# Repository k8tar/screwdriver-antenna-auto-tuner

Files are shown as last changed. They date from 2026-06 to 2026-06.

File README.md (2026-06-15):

# Screwdriver Antenna Auto Tuner

An ESP32-based automatic controller for motorized HF screwdriver antennas.

This repository contains the firmware, generated KiCad design files, enclosure
model, sourcing notes, build documentation, renders, and fabrication outputs for
an in-vehicle automatic antenna tuner with:

- ESP32 control logic
- OLED status display
- motor drive with current-based stall detection
- SWR measurement using an onboard directional coupler
- detachable radio and antenna harnesses
- Tarheel-style sensor support via the 4-wire antenna connector

## Current revision highlights

- single-mode auto-tuner firmware with TUNE, PARK, and jog controls
- power-stage revision to the Murata OKI-78SR fixed 3.3 V regulator
- external SWR jack removed from the PCB revision
- updated enclosure previews and board renders
- regenerated Gerber package in `fab/tuner_gerbers.zip`
- printable enclosure assets can be exported directly from OpenSCAD, with 3MF
	files generated for the current base and lid geometry

## Screenshots

Board render:

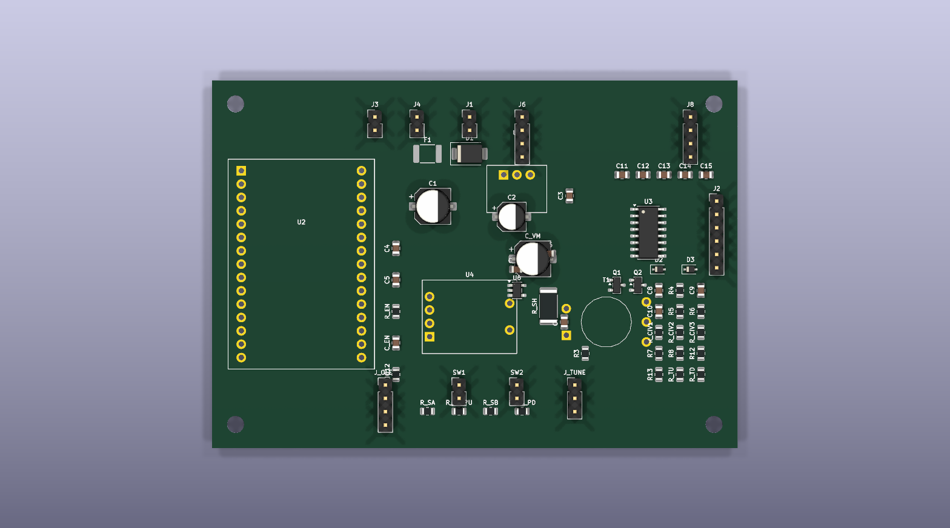
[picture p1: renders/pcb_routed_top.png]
Routed PCB top


Assembled enclosure preview:

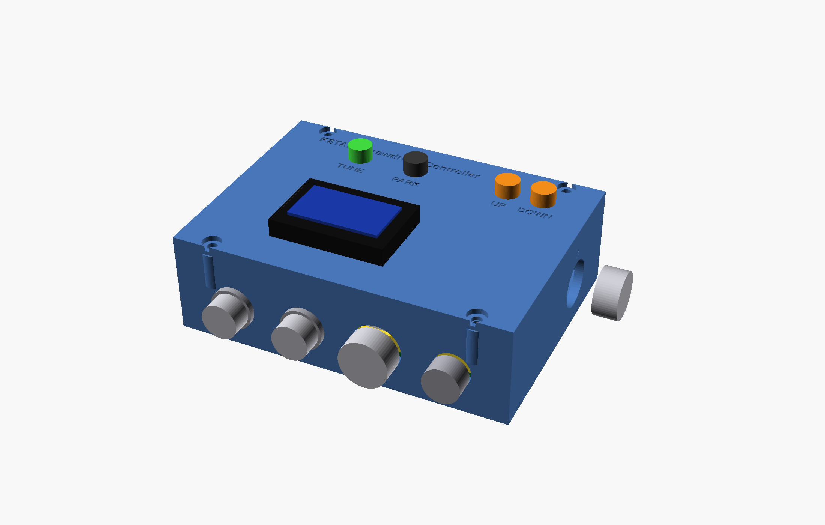
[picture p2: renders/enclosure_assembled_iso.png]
Enclosure assembled isometric


Service-open enclosure preview:

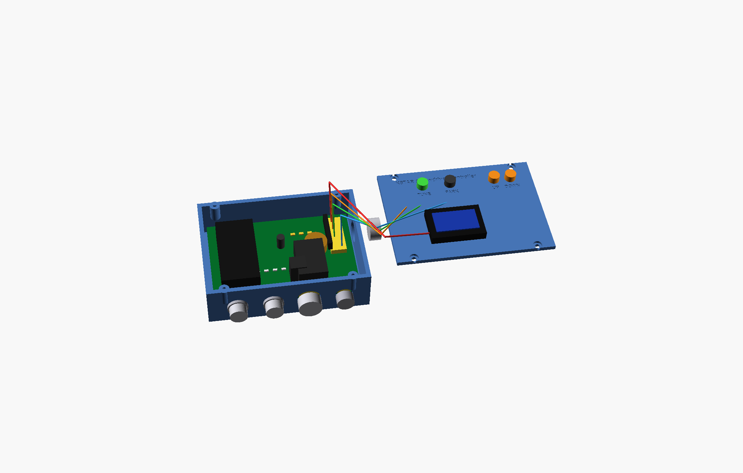
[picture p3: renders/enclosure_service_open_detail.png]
Enclosure service-open detail


## Repository layout

- `firmware/` — PlatformIO firmware, simulation wiring, and firmware spec
- `hardware/` — assembly guide, BOM, sourcing, routing notes, enclosure model
- `hardware/kicad/` — generated KiCad schematic, PCB, netlist, DSN, footprints
- `renders/` — board and enclosure images plus schematic and PCB PDFs
- `fab/` — generated Gerbers and fabrication ZIP package
- `scripts/` — source-of-truth generators for schematic, PCB, BOM, and fab outputs

## Quick start

1. Read the hardware requirements and build notes in `hardware/ASSEMBLY.md`.
2. Review the firmware contract in `firmware/FIRMWARE_SPEC.md`.
3. Build firmware from `firmware/` with PlatformIO.
4. If you are fabricating the PCB, use `fab/tuner_gerbers.zip`.
5. If you are printing the enclosure, use the generated 3MF files in
	`hardware/enclosure/` or export fresh parts from `hardware/enclosure/enclosure.scad`.

## First-time builder checklist

1. Read `hardware/ASSEMBLY.md` start to finish before soldering anything.
2. Confirm you are building the **Murata OKI-78SR** power-stage revision, not the older adjustable U1 variant.
3. Order parts from `hardware/BOM.csv` and review substitutions in `hardware/SOURCING.md`.
4. Verify your enclosure connector choices against `hardware/RADIO_CONNECTOR.md` and `hardware/enclosure/README.md`.
5. Print or export the enclosure parts you want before final panel-harness lengths are cut.
6. Build and test the firmware in `firmware/` before final in-vehicle installation.
7. Power the assembled board from a current-limited bench supply first.
8. Program the ESP32 DevKit over USB and verify the OLED, buttons, PARK, and jog behavior before connecting the antenna.
9. Run `PARK` once after wiring a Tarheel-style sensor harness so the controller establishes home.

## Prerequisites

- Python 3 for the generator scripts
- PlatformIO for firmware builds
- KiCad CLI available through the configured Flatpak commands for schematic/PCB regeneration
- OpenSCAD for enclosure previews and print-file export

## Build and generation

Firmware build:

```bash
cd firmware
pio run
```

Firmware upload:

```bash
cd firmware
pio run -t upload
pio device monitor
```

Hardware regeneration from the repo root:

```bash
python3 scripts/gen_footprints.py
python3 scripts/gen_schematic.py
flatpak run --command=kicad-cli org.kicad.KiCad sch export netlist -o hardware/kicad/tuner.net hardware/kicad/tuner.kicad_sch
flatpak run --command=python3 org.kicad.KiCad scripts/gen_pcb.py
flatpak run --command=python3 org.kicad.KiCad scripts/export_dsn.py
python3 scripts/gen_bom.py
python3 scripts/gen_gerbers.py
```

Enclosure print export:

```bash
cd hardware/enclosure
openscad -D 'part="base"' -o base.stl enclosure.scad
openscad -D 'part="lid"' -o lid.stl enclosure.scad
openscad -D 'part="both"' -o enclosure_full.stl enclosure.scad
openscad -D 'part="base"' -o base.3mf enclosure.scad
openscad -D 'part="lid"' -o lid.3mf enclosure.scad
openscad -D 'part="both"' -o enclosure_full.3mf enclosure.scad
```

## Primary documentation

- `firmware/FIRMWARE_SPEC.md`
- `firmware/src/README.md`
- `hardware/ASSEMBLY.md`
- `hardware/SOURCING.md`
- `hardware/RADIO_CONNECTOR.md`
- `hardware/enclosure/README.md`

## Fabrication outputs

- PCB fabrication ZIP: `fab/tuner_gerbers.zip`
- Individual Gerbers/drill files: `fab/gerbers/`
- Enclosure print files: `hardware/enclosure/base.stl`, `hardware/enclosure/lid.stl`, `hardware/enclosure/enclosure_full.stl`, `hardware/enclosure/base.3mf`, `hardware/enclosure/lid.3mf`, `hardware/enclosure/enclosure_full.3mf`
- Board and enclosure previews: `renders/`

## Programming the ESP32

This design uses an ESP32 DevKit module as `U2`, so the easiest programming path
is through the DevKit's normal USB port.

Typical workflow:

1. Assemble the board and fit the ESP32 DevKit at `U2`.
2. Power the board from a current-limited 12 V bench supply for first bring-up.
3. Connect the ESP32 DevKit USB port to your computer.
4. From the `firmware/` directory, run:

```bash
pio run -t upload
pio device monitor
```

If you ever need direct serial flashing instead of the DevKit USB connector, use
the debug UART header `J8` with a 3.3 V USB-to-UART adapter.

Recommended `J8` signals:

- pin 1 = GND
- pin 2 = 3V3
- pin 3 = TX from ESP32
- pin 4 = RX to ESP32

For most builds, you do **not** need to power the ESP32 through `J8`; just share
ground and use the DevKit USB interface unless you have a special recovery case.

## Notes

- The generated KiCad files in `hardware/kicad/` are derived artifacts; the
	Python scripts in `scripts/` are the source of truth.
- For vehicle use, internal board wiring should be direct-soldered and strain
	relieved rather than using loose jumper leads.
- The pre-generated STL and 3MF files are convenience outputs for the current
	enclosure geometry; regenerate them from `hardware/enclosure/enclosure.scad` if
	you change any enclosure parameters. `enclosure_full.3mf` and
	`enclosure_full.stl` contain the base and lid together as one combined export.

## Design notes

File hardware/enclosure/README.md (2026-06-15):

# Enclosure — 3D-printed, two-part

Parametric OpenSCAD box for the tuner PCB. **`enclosure.scad`** builds two parts:
a **base** tray (holds the PCB, carries the rear panel-mount connectors) and a
**lid** (the control panel — OLED, TUNE/PARK, jog).

## Dimensions
- Outer **110 × 80 × 34 mm** (fits the 100 × 70 board with 2 mm clearance).
- All driven by parameters at the top of the `.scad`; change `board_l/w`,
  `comp_clear` (headroom), `gap`, `wall`, `standoff_h` and everything re-derives.

## Rendering / exporting
```
openscad -D 'part="base"' -o base.stl  enclosure.scad
openscad -D 'part="lid"'  -o lid.stl   enclosure.scad
openscad -D 'part="both"' -o enclosure_full.stl enclosure.scad
openscad -D 'part="base"' -o base.3mf enclosure.scad
openscad -D 'part="lid"'  -o lid.3mf  enclosure.scad
openscad -D 'part="both"' -o enclosure_full.3mf enclosure.scad
# preview both side-by-side in the GUI: set part="both"
```

Pre-generated print files for the current repo revision:

- `base.stl`
- `lid.stl`
- `enclosure_full.stl` (base and lid exported together in one STL)
- `base.3mf`
- `lid.3mf`
- `enclosure_full.3mf` (base and lid exported together in one 3MF)

Additional preview modes in `enclosure.scad`:

- `part="assembled"` closed enclosure with installed board/components
- `part="lid_off"` lifted lid with wiring still connected
- `part="service_open"` lid fully moved to the side with long service loops

RF connector cutout in `enclosure.scad` is fixed for compact Mini-UHF bulkheads:

- `rf_bulkhead_d = 10.0` (Mini-UHF panel hole)
- Selected connector model: **Amphenol RF 172147** (Mouser)

Optional RF mounting screw-hole pattern:

- `rf_mount_holes = true` enables two M3 clearance holes per RF connector.
- `rf_mount_hole_d` sets the screw hole diameter.
- `rf_mount_hole_pitch` sets screw center-to-center spacing.

Set `rf_mount_holes = false` if your Mini-UHF connector uses only a threaded
bushing + nut and no flange screws.

Default in this repo is `rf_mount_holes = false` because Amphenol RF 172147 is a
threaded bulkhead style.

## What's on each part
**Base — rear wall (panel-mount, wired by flying lead to the board headers):**
| Cutout | Ø | For |
|---|----|-----|
| RF IN | 10 mm | Mini-UHF bulkhead → board J3 |
| RF OUT | 10 mm | Mini-UHF bulkhead → board J4 |
| RADIO | 16 mm | **GX16 bulkhead** → board J2 (universal radio, see `../RADIO_CONNECTOR.md`) |
| POWER | 12 mm | 12 V panel jack → board J1 |

**Base — right side wall:** an antenna connector cutout (GX16-4 style, → J6). Vent slots on the
left side wall (buck/motor heat).

**Lid — control panel (panel-mounted UI, wired to the board headers):**
OLED window (30 × 17), two button holes (Ø6: TUNE / PARK), and **two momentary
jog button holes** (Ø6: UP / DOWN). These are a clean ergonomic layout — the
parts mount on the lid and connect by flying lead to the J_OLED / SW1 / SW2 /
J_TUNE headers, so the lid layout is independent of where those headers sit on
the PCB. The current lid revision also includes:

- a mostly hollow rear OLED recess with a thin front lip for glue/tape mounting
- direct through-holes for the buttons and jog switches so switches can be
  mounted/glued from the back with wires soldered directly on the tabs
- lid screw clearance bores that continue through the locating lip so the screws
  actually pass into the base bosses
- engraved text in the lid for title and control labels, plus connector labels
  around the enclosure bulkhead cutouts

## Assembly
1. Screw the PCB onto the 4 floor standoffs (M3 × 6, from above).
2. Mount the panel connectors in the rear wall; solder their flying leads to the
   matching board headers (keep RF leads short; see RADIO_CONNECTOR.md for J2).
3. Fit the lid; secure with 4 × M3 into the corner bosses.
4. PCB mounting holes are at board (4.5, 4.5) (95.5, 4.5) (4.5, 65.5) (95.5, 65.5)
   — identical to `scripts/gen_pcb.py` HOLES, so the standoffs always line up.

## Print settings
- **Material:** PETG (recommended — survives a hot cab). PLA only for bench use.
- 0.2 mm layers, 3 perimeters, 20–30 % infill.
- Base prints open-side up (no supports). Lid prints face-down (cutouts need no
  support). Self-tapping M3 into the printed bosses; or melt in M3 heat-set
  inserts for repeated assembly (bump boss pilot to Ø4.0 for inserts).

## ⚠️ Verify before printing
- The UI is treated as **panel-mounted** (OLED, TUNE/PARK buttons, jog rocker on
  the lid, wired to headers). If you change panel components, verify body depth
  and nut clearances against `comp_clear`.
- The BOM's tactile buttons are the **right-angle** PTS645 variant; for a
  lid-mounted panel use **vertical** tactiles or separate panel buttons.
- Confirm `comp_clear` (20 mm headroom) against your tallest assembled part
  (ESP32 DevKit on its socket + the bulk caps).

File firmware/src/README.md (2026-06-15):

# ESP32 Screwdriver Tuner Firmware

This firmware implements the updated pure auto-tuner behavior from `firmware/FIRMWARE_SPEC.md`.

Current layout:

- `firmware/platformio.ini`
- `firmware/src/main.cpp`
- `firmware/wokwi.toml`
- `firmware/diagram.json`

## Build and flash

Run commands from the `firmware/` directory:

```bash
pio run
pio run -t upload
pio device monitor
```

## Wokwi simulation

1. Build once:

```bash
pio run
```

2. Open `firmware/diagram.json` in VS Code.
3. Start simulator with `Wokwi: Start Simulator`.

### Sim control mapping

- `TUNE` button -> GPIO32
- `PARK` button -> GPIO33
- `UP` rocker/button -> GPIO22
- `DOWN` rocker/button -> GPIO23
- SWR forward pot -> GPIO34
- SWR reflected pot -> GPIO35
- Motor current sense pot -> GPIO27
- Motor direction LEDs -> GPIO25 / GPIO26
- OLED SSD1306 I2C -> GPIO4 (SDA), GPIO5 (SCL)

### Sim notes

- The simulator does not emulate complete CAT/CI-V radio behavior.
- You can still validate UI, debounce behavior, motor state transitions, stall handling, and SWR search flow.

## Firmware behavior summary

- Single operating model (no AUTO/SEMI/MANUAL mode switch).
- No hall sensor position tracking.
- No memory slot / band memory feature.
- `TUNE`:
  - Attempts low-power keyed carrier via detected radio protocol.
  - Sweeps motor, using SWR trend and stall detection to locate a dip.
  - Returns to best point and finishes with status (`TUNE OK`, `TUNE DONE`, `NO DIP`, etc.).
- `PARK`:
  - Drives downward until stall/end-stop and then stops.
- `UP`/`DOWN`:
  - Manual jog while held.

## Important bring-up checks

1. Verify INA180 + shunt scaling for motor current threshold.
2. Tune stall threshold (`stallA`) for your mechanical system.
3. Validate detector offsets/gains against your coupler hardware.
4. Confirm CAT/CI-V command compatibility with your radio model.

## Notes

- GPIO12 remains input-only in firmware.
- GPIO34/35 are treated as ADC inputs only.

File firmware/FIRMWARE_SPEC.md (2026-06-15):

# ESP32 Screwdriver Antenna Tuner — Firmware Specification

This is a **self-contained** implementation spec for the firmware. The hardware
(schematic + 4-layer PCB) is complete and frozen; this document is the contract
between it and the firmware. Implement to this; don't assume access to other
project files except where referenced.

> **Revision (single-mode auto-tuner):** the design is a **single-mode automatic
> tuner** — no operating-mode switch, no rotary encoder, and no memory buttons.
> The controls are **TUNE**, **PARK**, a **jog rocker**, and the OLED. The board
> also exposes an **optional 2-wire antenna pulse-feedback input** for Tarheel-style
> sensors. Firmware must still work when no sensor pulses are present by falling
> back to the original stall-only sweep behavior.

---

## 1. What the product does

A controller for a **motorized "screwdriver" HF antenna** (a variable inductor
whose resonance is changed by a DC motor). It drives the motor to the **lowest
SWR**, automatically, with the radio in the loop:

**Core tune sequence** — triggered by the front-panel **TUNE** button *or* by the
radio requesting a tune over CAT/CI-V:
1. Command the radio (over CAT/CI-V) to **drop to minimum power (~1 W)** and key a
   carrier (or AM/FM/CW tune tone).
2. **Sweep the motor** while reading SWR; find the position of lowest SWR
  (gradient/hill-climb — §10). Detect mechanical travel limits by **motor stall
  current** and, when pulse feedback is available, use that count to return to
  the best point more accurately.
3. **Unkey** and **restore the radio's previous power level.**
4. Show the result (final SWR) on the OLED.

Other controls: **PARK** drives the antenna fully **down** to the bottom end-stop
(for travel/stowing); the **jog rocker** moves the motor up/down by hand for setup.
SWR is measured with an on-board Bruene directional coupler. The firmware
**auto-detects which radio brand/protocol is attached** (Icom CI-V / Kenwood /
Yaesu). There is **no band memory** — every tune is a fresh sweep.

---

## 2. Target hardware & toolchain

- **MCU:** ESP32-WROOM-32E on a 30-pin DevKit (DOIT/NodeMCU-32S), 3.3 V logic.
- **Recommended framework:** **Arduino-ESP32 via PlatformIO** (rich libraries:
  U8g2 for the OLED, hardware UARTs, LEDC PWM, Preferences/NVS). ESP-IDF is
  acceptable if preferred; this spec is framework-neutral.
- **Suggested libraries:** `U8g2` (SSD1306), `Preferences` (NVS). No heavyweight
  CAT library is assumed — protocol handling is small and is specified below.

---

## 3. Pin map (authoritative — taken from the netlist)

| GPIO | Net | Function | Direction / peripheral |
|-----:|-----|---|---|
| 4  | I2C_SDA | OLED SSD1306 data | I2C0 SDA |
| 5  | I2C_SCL | OLED SSD1306 clock | I2C0 SCL |
| 16 | RADIO_RX | CAT receive (from MAX3232 ROUT) | **UART2 RX** |
| 17 | RADIO_TX | CAT transmit (to MAX3232 TIN) | **UART2 TX** |
| 13 | CIV_TX | CI-V transmit (to transistor buffer) | **UART1 TX** |
| 14 | CIV_RX | CI-V receive (from transistor buffer) | **UART1 RX** |
| 25 | MTR_IN1 | DRV8871 IN1 | LEDC PWM out |
| 26 | MTR_IN2 | DRV8871 IN2 | LEDC PWM out |
| 27 | MTR_ISENSE | motor current (INA180 out) | **ADC1** in |
| 34 | SWR_FWD | forward detector voltage | **ADC1** in (input-only) |
| 35 | SWR_REV | reflected detector voltage | **ADC1** in (input-only) |
| 36 | ANT_SENSE_A | antenna pulse feedback A | input-only |
| 39 | ANT_SENSE_B | antenna pulse feedback B / return sense | input-only |
| 32 | BTN_TUNE | TUNE button (start a tune) | input, active-low |
| 33 | BTN_PARK | PARK button (drive to bottom end-stop) | input, active-low |
| 22 | TUNE_UP | jog rocker up (10k pull-up) | input, active-low |
| 23 | TUNE_DOWN | jog rocker down (10k pull-up) | input, active-low |
| 1  | DBG_TX | debug/console (J8) | UART0 TX |
| 3  | DBG_RX | debug/console (J8) | UART0 RX |
| 12 | IO12_STRAP | **boot strap, 10k pulldown — leave as input, do NOT drive high at boot** | — |
| 18, 19, 21, 2, 15 | (NC) | **spare** | — |

Notes:
- BTN_TUNE/BTN_PARK have **external** 10k pull-ups (R7/R8); the jog rocker pins
  have external 10k pull-ups (R_TU/R_TD). All four are **active-low**.
- GPIO34/35/36/39 are **input-only**.
- GPIO12 is a boot strapping pin; the board pulls it down. Configure as input.
- The antenna feedback pair is biased on-board for a **pulse/contact-style**
  sensor. If no pulses appear, firmware must fall back to stall-only behavior.

---

## 4. Peripheral configuration

### 4.1 OLED display
- SSD1306 128×64 over I2C0 (SDA=4, SCL=5), default address `0x3C`. Plugs into
  `J_OLED`. Use U8g2 (page or full buffer). ~30 fps is plenty.

### 4.2 CAT UART (Yaesu / Kenwood) — UART2
- GPIO17 = TX → MAX3232 → radio RXD; GPIO16 = RX ← MAX3232 ← radio TXD.
- True RS-232 levels are handled by the on-board MAX3232; firmware just uses TTL
  UART2. **8N1.** Baud is discovered (see §7). Idle non-inverted (RS-232 path).

### 4.3 CI-V UART (Icom) — UART1
- GPIO13 = TX, GPIO14 = RX, through a 2-transistor open-drain buffer to a single
  half-duplex 5 V-tolerant bus.
- **The buffer inverts the signal — configure UART1 inverted** (invert both TX and
  RX) so the line idles correctly. (Verify polarity on a scope on first bring-up;
  if framing is garbage, toggle the invert flags.) **8N1.**
- Single-wire half-duplex: you will read back your own transmitted bytes (echo) —
  discard the echo before parsing the reply.

### 4.4 ADC inputs
- Use ADC1 (ADC2 is unusable when Wi-Fi is on). 12-bit, 11 dB attenuation
  (0–~3.3 V). **Oversample/average** (e.g., 32–64 samples) — SWR DC lines are slow.
- `SWR_FWD` (34), `SWR_REV` (35): detector DC after the Schottky + RC filter.
- `MTR_ISENSE` (27): INA180A1 output = `I_motor × 0.05 Ω × 20` (gain 20). So
  **A per volt = 1 / (0.05 × 20) = 1.0 A/V** at the ADC.

### 4.5 Motor PWM (DRV8871 carrier)
- IN-IN drive: to go one direction PWM `MTR_IN1` while `MTR_IN2`=0; reverse =
  PWM `MTR_IN2` while `MTR_IN1`=0; brake = both high; coast = both low.
- LEDC, **~20 kHz** (above audio), 8–10 bit duty. Hardware current limit is set
  by the carrier (ILIM resistor); firmware adds soft-start and stall logic (§9).

### 4.6 Position feedback
- Optional **2-wire pulse feedback** on `ANT_SENSE_A` (36) / `ANT_SENSE_B` (39).
- Hardware biasing assumes a **dry contact or open-collector pulse pair** from the
  antenna harness. Firmware should count pulses while the motor is moving.
- `PARK` still bottoms the antenna by **stall current**. After a successful park,
  firmware should treat the current pulse count as **home = 0** and then use pulse
  counts for relative positioning during later tune sweeps.
- If no pulses are ever observed, firmware must revert to the original stall-only,
  time-step tune algorithm.

### 4.7 Front-panel controls (all active-low, external 10k pull-ups)
- `BTN_TUNE` = 32 — start a tune sequence (§6).
- `BTN_PARK` = 33 — drive the antenna fully **down** to the bottom end-stop, then
  stop. Long-hold not required; a single press runs the park to completion (abort
  on any other control or stall-confirmed limit).
- Jog rocker `J_TUNE`: `TUNE_UP` = 22 / `TUNE_DOWN` = 23, **momentary** (motor runs
  only while held). Debounce all buttons ~20 ms.

---

## 5. System architecture

A cooperative loop or a few FreeRTOS tasks — either is fine. Suggested split:

- **UI task / loop (≈30 Hz):** read the buttons + jog rocker, render OLED.
- **Measurement (≈50–100 Hz):** average ADCs → Vfwd, Vrev → SWR; read current.
- **Motor control (≈1 kHz service):** ramp PWM, stall watchdog.
- **Radio task:** detect the rig at boot; poll for a tune request; issue power/key
  commands during a tune.
- **Tune/park state machine:** orchestrates the sequences in §6.

Keep motor commands funnelled through one `motor_set(direction, duty)` so the
stall watchdog and limit logic can't be bypassed.

---

## 6. Operation (single mode — there is no mode switch)

The unit sits **IDLE** showing SWR/status until a trigger occurs.

### TUNE  (trigger: `BTN_TUNE`, or a radio tune-request — §7)
The firmware drives the whole sequence, controlling the radio over CAT/CI-V:
1. **Read & remember** the radio's current power level (so it can be restored).
2. **Set power to minimum (~1 W)** and **key a carrier** (CW/AM/FM tune tone — the
   command set per protocol is in §7). If there is no radio (or it can't be
   commanded), instead prompt on the OLED "KEY CARRIER" and proceed once forward
   power is detected.
3. Wait for forward power, then run the **SWR sweep** (§10.1): sweep the motor,
   track SWR, home in on the minimum. Travel ends are found by **stall current**.
4. **Unkey**, **restore the saved power level**, and BRAKE the motor at the dip.
5. Show the final SWR (and "TUNE OK" / "NO DIP" / "TIMEOUT").
- **Abort** on any button/jog press, loss of forward power, or the time-box (§15);
  always unkey and restore power on abort.

### PARK  (trigger: `BTN_PARK`)
- Drive the motor **down** continuously until the bottom **stall** end-stop, then
  BRAKE. This fully retracts the antenna for travel/stow. Abort on any other press.

### JOG  (trigger: jog rocker held)
- While `TUNE_UP`/`TUNE_DOWN` held → motor up/down (ramped); release → BRAKE. Show
  the **live SWR meter** while jogging. For manual bench setup/override.

No menus, no encoder, no memory. Calibration (§8) and "re-scan radio" are entered
by a **TUNE + PARK chord held at power-up** (or over the debug console).

---

## 7. Radio interface & auto-detection

Two independent UARTs let you probe both buses. **Detection runs at boot** (and
from the menu's "Re-scan"). Result (brand, protocol, baud, CI-V address) is cached
in NVS so later boots skip the scan unless "forget radio" is chosen.

### Detection algorithm
```
for baud in [19200, 9600, 4800]:                 # CI-V (UART1, inverted)
    send CI-V read-frequency (cmd 0x03) to addr 0x00 (broadcast) from 0xE0
    if a valid CI-V frame (FE FE … FD) returns:  -> ICOM, store responding addr & baud
for baud in [9600, 4800, 38400, 57600, 115200]:  # CAT (UART2)
    send Kenwood "ID;"        -> "ID019;" etc.    -> KENWOOD, decode model id, store baud
    send Yaesu read (model-appropriate, see below)
    if a valid reply:                             -> YAESU, store baud
if nothing answered: radio = NONE (AUTO degrades to SEMI)
```
Probe CI-V and CAT concurrently if convenient (separate UARTs). Use short
per-attempt timeouts (~150 ms) and a couple of retries.

### CI-V (Icom)
- Frame: `FE FE <to> <from> <cmd> [data] FD`. Controller address `0xE0` (default).
- Read frequency: cmd `0x03`; reply data is BCD frequency, little-endian by byte.
- Discard the half-duplex echo of your own frame before reading the reply.
- Default radio address depends on model (e.g. 0x94, 0xA2, 0x76…); during
  detection use broadcast `0x00` and learn the responder's `<from>` address.

### Kenwood CAT
- ASCII, terminated by `;`. **`ID;` → `IDnnn;`** is the cleanest fingerprint
  (returns a numeric model code). Read frequency: **`FA;` → `FAxxxxxxxxxxx;`** (11
  digits, Hz). Typical bauds 9600/57600.

### Yaesu CAT
- Varies by model. Newer rigs (FTDX/FT-991/FT-891) accept Kenwood-style ASCII
  (`FA;`, `ID;`) — treat "responds to ASCII but ID differs from Kenwood codes" as
  Yaesu. Older FT-817/857/897 use a 5-byte binary CAT (last byte = opcode, e.g.
  `0x03` read-freq returns BCD) at 4800/38400 — implement this as a secondary
  Yaesu path. Make the per-model command set a small table so radios are easy to add.

**Adding a radio later = new cable + a protocol-table entry; no hardware change.**

### Radio TX control during a tune (the core mechanism)
Each protocol entry must also provide **power read/set** and **key/unkey** so the
TUNE sequence (§6) can run hands-free. Save the current power, set ~1 W, key, sweep,
unkey, restore. Per protocol:
- **Icom CI-V:** power = cmd `0x14 0x0A` (read) / `0x14 0x0A <bcd>` (set, 0000–0255
  scaled to 0–100 %); set near the minimum. Key/unkey = cmd `0x1C 0x00 0x01/0x00`
  (PTT on/off). Pick a mode the rig emits carrier in (CW/AM/RTTY/FM) via `0x06`.
- **Kenwood:** power `PC;`/`PCxxx;`; key/unkey `TX;`/`RX;`. (Use CW/FM for a steady
  carrier.)
- **Yaesu:** newer rigs `PC;`/`PCxxx;` + `TX1;`/`TX0;`; FT-8x7 binary opcodes for
  PTT and (limited) power.
- **No-radio fallback:** can't command power/key → prompt the operator to set low
  power and key manually; start the sweep when forward power is seen, and just show
  "UNKEY" when done. **Time-box the keyed period** (e.g. ≤ a few seconds of search,
  hard cap) and **always send unkey + restore power** on completion *and* on abort.

> Tune-request trigger: simplest is the front-panel TUNE button. If you also want
> the rig to start it, watch for the radio's tuner-request over CAT (model-specific)
> or a band/frequency change — but the button is the guaranteed path.

---

## 8. SWR measurement & calibration

The coupler outputs two DC voltages proportional to forward and reflected RF
(Schottky-detected, RC-filtered). After averaging the ADCs:

```
Vf = adc_volts(SWR_FWD)        # detected forward
Vr = adc_volts(SWR_REV)        # detected reflected
# correct for Schottky offset/curvature with a calibration function f():
Pf = detector_to_power(Vf)     # see calibration
Pr = detector_to_power(Vr)
gamma = sqrt(Pr / Pf)          # reflection coefficient magnitude (0..1)
SWR   = (1 + gamma) / (1 - gamma)     # clamp gamma < ~0.99
```
- Guard against `Vf` near zero (no carrier) — report "no RF" and never act on a
  divide-by-zero.
- **Calibration routine** (menu): with a known load (50 Ω → SWR 1.0, and an open
  or known mismatch), capture detector readings to fit `detector_to_power()`
  (a simple piecewise/quadratic fit handles the Schottky knee). Store coefficients
  in NVS. A usable default: treat the detector as square-law above the knee and
  linear below; ship reasonable defaults so it works uncalibrated, refine in cal.
- Display SWR as a bargraph (1.0–3.0+ zoomed) plus numeric (e.g. "1.4:1").

---

## 9. Motor control & end-stops (no position sensor)

- `motor_set(dir, duty)`: dir ∈ {UP, DOWN, BRAKE, COAST}; duty 0–max. Soft-start
  ramp (~100–200 ms) on direction changes.
- **Stall / end-stop detection** is the only travel-limit mechanism: read
  `MTR_ISENSE` (1.0 A/V); if current exceeds a threshold (~1.5× free-running tune
  current, tuned empirically) for > ~150 ms, treat it as a mechanical end-stop:
  BRAKE immediately. PARK drives DOWN to that stall; the sweep reverses off a stall.
- There is **no absolute position** — the sweep works on the SWR gradient, not
  coordinates. Always **BRAKE** (not COAST) to hold the antenna at the found dip.
- Never dwell against a stall (heat / driver fault) — back off and BRAKE.

---

## 10. Tuning algorithm (SWR sweep)

1. Confirm forward power present (carrier on — §6/§7).
2. **Coarse sweep:** move one direction at moderate duty, sampling SWR; if SWR
   rises steadily (or a stall end-stop is hit), reverse. Remember the lowest SWR and
   roughly where it was (by time/step count since the last reversal).
3. **Fine search:** creep back toward the minimum at low duty and hill-climb
   (step, measure, reverse a step if worse) until SWR < target (default 1.3:1) or
   the step size bottoms out.
4. **BRAKE** at the minimum.
- **Time-box** the keyed search (§15) and abort cleanly on any button/jog press or
  loss of carrier — always unkey + restore radio power on exit (§7).

---

## 11. Persistent storage (NVS)

Minimal — **no band memory**. Use `Preferences`/NVS for:
- `radio`: `brand`, `proto`, `baud`, `civ_addr`, `detected` flag (cached so boot
  skips re-detection).
- `cal`: detector calibration coefficients, SWR target (default 1.3), stall-current
  threshold.

Keep writes infrequent (NVS wear) — only on a successful detect or calibration.

---

## 12. UI

### 12.1 Screens
- **Idle/Main:** big **SWR** (bargraph + numeric), frequency (if a radio is read),
  detected radio brand, and status (READY / TUNING / PARKED / NO RADIO).
- **Tuning:** live SWR while sweeping + an abort hint.
- **Park:** "PARKING…" then "PARKED".

### 12.2 Controls recap
- **TUNE** = start an auto tune. **PARK** = retract antenna to the bottom stop.
- **Jog rocker** = manual up/down (motor runs only while held), live SWR shown.
- **TUNE+PARK held at power-up** = enter calibration / re-scan radio (or use the
  debug console). No encoder, no menus, no memory.

---

## 13. Boot sequence

1. Init NVS, I2C/OLED (splash), UARTs (UART1 inverted for CI-V), ADC, LEDC, ISRs.
2. Load cal + radio + memories from NVS.
3. If no cached radio → run detection (§7) with an on-screen "Detecting radio…".
4. Read mode switch; enter that mode's idle state. Motor stays stopped until
   commanded. Show main screen.

---

## 14. Safety & fault handling

- **Motor:** enforce end-stops; stall-current cutoff; always BRAKE to stop; ramp
  duty; refuse motion if `MTR_ISENSE` reads implausibly high at rest (driver fault).
- **No-carrier guard:** never run a seek without detected forward power.
- **Watchdog:** feed the hardware WDT; ensure the motor is stopped in any fault/
  reset path (motor must not latch on across a crash — default both IN pins low).
- **GPIO12** must remain an input (boot strap); never drive it at reset.
- Brown-out: rely on ESP32 BOD; on under-voltage, stop the motor.

---

## 15. Tunable constants (surface these as named defines)

PWM freq (20 kHz), PWM max duty, soft-start ms, stall current (A) & debounce ms,
SWR target (1.3), seek step size & timeout (30 s), ADC averaging (32–64), button
debounce (20 ms), CAT/CI-V timeouts & baud lists, memory slot granularity.

---

## 16. Milestones / acceptance criteria

1. **Bring-up:** OLED splash; buttons/encoder/rocker read correctly; mode switch
   resolves 3 positions; debug console on UART0.
2. **Motor:** jog up/down with ramp; stall detection trips on end-stop; position
   counter increments; homing works.
3. **SWR:** Vfwd/Vrev read; SWR computed and displayed; calibration routine stores
   coefficients; "no RF" handled.
4. **SEMI:** null-seek reliably finds the SWR minimum on the bench (signal
   generator + adjustable mismatch) within the timeout.
5. **Radio:** auto-detect identifies Icom (CI-V), Kenwood (`ID;`), and a Yaesu rig;
   frequency read works; result cached in NVS.
6. **AUTO:** frequency change triggers recall + fine-trim; positions persist across
   power cycles.
7. **Robustness:** no motor runaway on faults; WDT clean; NVS writes bounded.

---

## 17. Verify against hardware before/while coding

- **CI-V invert polarity** on GPIO13/14 (scope; flip invert flags if needed).
- **MODE_SW levels** (§12.3) — exact divider taps.
- **Hall pulse** electrical level/threshold on GPIO36 and pulses-per-revolution.
- **Detector transfer curve** for the BAT46 detectors (calibration).
- **Motor stall current** of the specific antenna (set the threshold empirically).
- Pin map above is from the netlist and is authoritative; cross-check once on the
  first assembled board.

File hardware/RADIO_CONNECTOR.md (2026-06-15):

# Universal Radio Connector — wiring, cables & auto-detection

One panel-mounted connector handles **all** supported radios. You build a short
adapter cable per radio; the firmware figures out which radio is attached by
probing. Kenwood and Yaesu are electrically identical (RS-232 CAT) and are told
apart in software.

---

## 1. Signal set (what the board provides)

The board exposes the radio signals on header **J2 (`RADIO_UNIVERSAL`, 1×06)**,
which you wire with flying leads to a **panel bulkhead connector** (recommended:
**GX16 aviation**, 6- or 8-pin). Nothing radio-specific lives on the PCB — the
cable does the adapting.

| J2 pin | Net | Direction | Used by |
|:---:|-----|---|---|
| 1 | `GND` | — | all |
| 2 | `RS232_TX` | board → radio RXD | Yaesu / Kenwood CAT (via U3 MAX3232) |
| 3 | `RS232_RX` | radio TXD → board | Yaesu / Kenwood CAT |
| 4 | `CIV_BUS` | bidirectional | Icom CI-V (via Q1/Q2 TTL buffer) |
| 5 | `+3V3` | board → cable | optional power for an active cable |
| 6 | `GND` | — | shield / 2nd ground |

`RS232_TX/RX` are **true RS-232 levels** (±5–10 V) out of the MAX3232.
`CIV_BUS` is **single-wire 5 V-tolerant TTL**, open-drain, half-duplex.
**Never wire CI-V to the RS-232 pins** — different electrical standards.

---

## 2. Panel connector (GX16) — recommended pinout

Wire J2 → GX16 1:1 so every cable sees the same panel pinout:

| GX16 pin | Signal | GX16 pin | Signal |
|:---:|---|:---:|---|
| 1 | GND | 4 | CIV_BUS |
| 2 | RS232_TX | 5 | +3V3 |
| 3 | RS232_RX | 6 | GND |

GX16 mounts through a ~16 mm hole in the printed enclosure, locks with a knurled
ring, and is keyed so the cable can only insert one way. A GX16-8 gives two spare
pins for future expansion (e.g. PTT or a CABLE_ID resistor).

> **Bulkhead wiring:** keep the J2-to-GX16 flying leads short and twist
> RS232_TX/RX together and CIV/GND together. If you ever see RF pickup on the
> CI-V line during TX, add a clip-on ferrite on the radio cable.

---

## 3. Per-radio adapter cables

Each cable is **GX16 plug → radio's connector**. Only the pins that radio needs
are populated; the rest are left unconnected.

### Cable parts list (per this repo BOM)

Use these offboard BOM items when building cable sets:

- `P_RADIO_GX16_PANEL` x1: enclosure panel bulkhead (board side)
- `P_RADIO_GX16_PLUG` x1 per cable: cable-side GX16 male plug
- `W_RADIO_CTRL`: shielded multicore cable stock
- `P_CIV_3P5MM`: Icom CI-V termination plug
- `P_CAT_MINIDIN8`: Yaesu CAT termination plug
- `P_CAT_DB9F`: Kenwood CAT termination connector

If a radio uses a different CAT plug than the defaults above, substitute that
radio-end connector and keep the GX16 pin mapping in Section 2 unchanged.

### Icom (CI-V) — 3.5 mm mono/stereo plug
| GX16 | → | Radio CI-V jack |
|---|---|---|
| 4 (CIV_BUS) | → | tip (CI-V data) |
| 1 (GND) | → | sleeve (ground) |

### Yaesu (CAT, RS-232) — e.g. mini-DIN / CAT jack, varies by model
| GX16 | → | Radio CAT |
|---|---|---|
| 2 (RS232_TX) | → | radio **RXD / CAT-IN** |
| 3 (RS232_RX) | → | radio **TXD / CAT-OUT** |
| 1 (GND) | → | ground |

### Kenwood (CAT, RS-232) — e.g. DB-9 / 6-pin DIN, varies by model
| GX16 | → | Radio CAT |
|---|---|---|
| 2 (RS232_TX) | → | radio **RXD (pin 2 on a DB-9 male radio)** |
| 3 (RS232_RX) | → | radio **TXD (pin 3)** |
| 1 (GND) | → | ground (pin 5) |

> Yaesu and Kenwood cables are wired the **same way** electrically — the only
> difference is the connector on the radio end and the CAT command set. Watch
> TX/RX direction: it's always **board-TX → radio-RX** (a null-modem swap if the
> radio is DTE). If you get no response, swap pins 2↔3 at the radio end.

Some rigs (older Yaesu FT-8x7, etc.) expose **TTL-level** CAT, not RS-232. For
those, put a small TTL↔RS-232 adapter (or a level shifter) **in the cable**, and
use pin 5 (+3V3) / pin 1 (GND) to power it. That's exactly what the spare power
pin is for.

---

## 4. Firmware auto-detection (probe sequence)

The two interfaces are on independent UARTs, so the firmware can probe both
without any hardware switching:

- **CI-V** → ESP32 UART1 (GPIO13/14) → Q1/Q2 buffer → `CIV_BUS`
- **CAT**  → ESP32 UART2 (GPIO16/17) → MAX3232 → `RS232_TX/RX`

Detection routine on boot (and on a "re-scan" menu item):

```
for baud in [CI-V 19200, 9600, 4800]:
    send CI-V "read frequency" (cmd 0x03) to broadcast addr 0x00
    if valid CI-V frame returns  ->  ICOM, remember the responding address
for baud in [9600, 4800, 38400, 57600, 115200]:
    send Kenwood "ID;"           # returns "ID019;" etc.
    if "ID" response             ->  KENWOOD, decode model id
    send Yaesu read-status / read-freq (model-appropriate)
    if valid response            ->  YAESU
-> none responded: stay in MANUAL / SEMI-AUTO (SWR-only) mode
```

Notes that make this reliable:
- **Kenwood `ID;`** is the cleanest fingerprint — it returns a numeric model
  code, so you get exact identification, not just "a Kenwood."
- **Icom** is identified by *any* CI-V reply; capture the source address so you
  can address it directly afterwards.
- **Yaesu** varies most by model — start with the common FT-8x7/9x7/DX command
  forms; treat "responds to CAT but not Kenwood ID" as Yaesu.
- Probe CI-V and CAT **concurrently** (both UARTs listening) to cut detect time.
- Cache the detected radio + baud in NVS so subsequent boots skip the scan
  (with a "forget radio" option in the menu).

This belongs in the firmware stage; the hardware already routes both interfaces
to the single universal connector, so no board change is needed to add radios —
only new cables and new protocol handlers.

---

## 5. Summary

- **One** bulkhead connector (GX16) on the enclosure, wired remotely from J2.
- **Passive** per-radio cables (except optional TTL-CAT level shifter).
- Adding a radio = new cable + firmware protocol, **no PCB change**.
- Kenwood support is firmware-only (same RS-232 path as Yaesu).

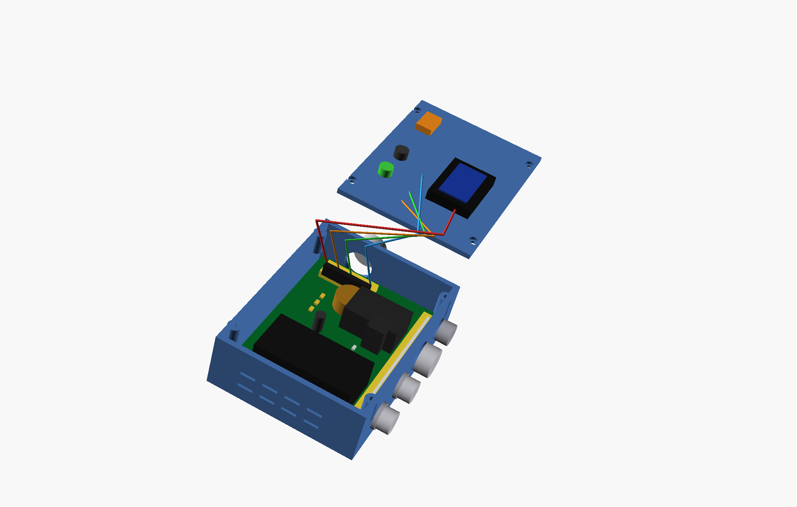
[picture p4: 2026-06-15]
renders/enclosure_service_open_side.png

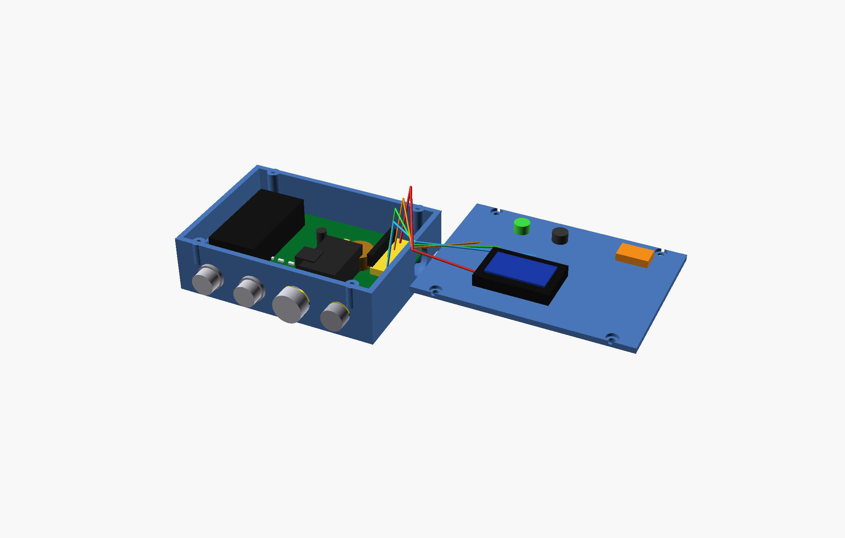
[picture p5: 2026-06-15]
renders/enclosure_service_open_iso.png

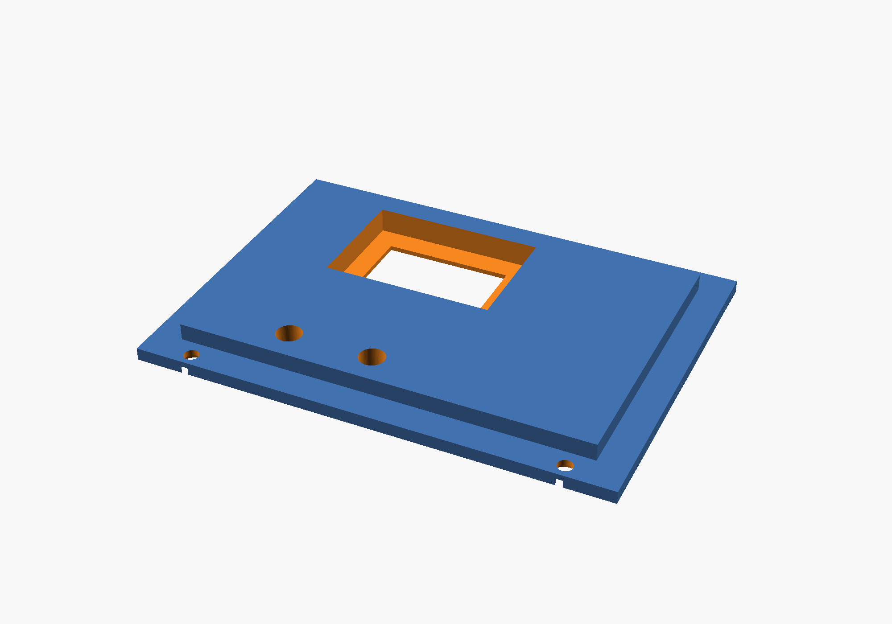
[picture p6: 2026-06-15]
renders/enclosure_lid_underside_check.png

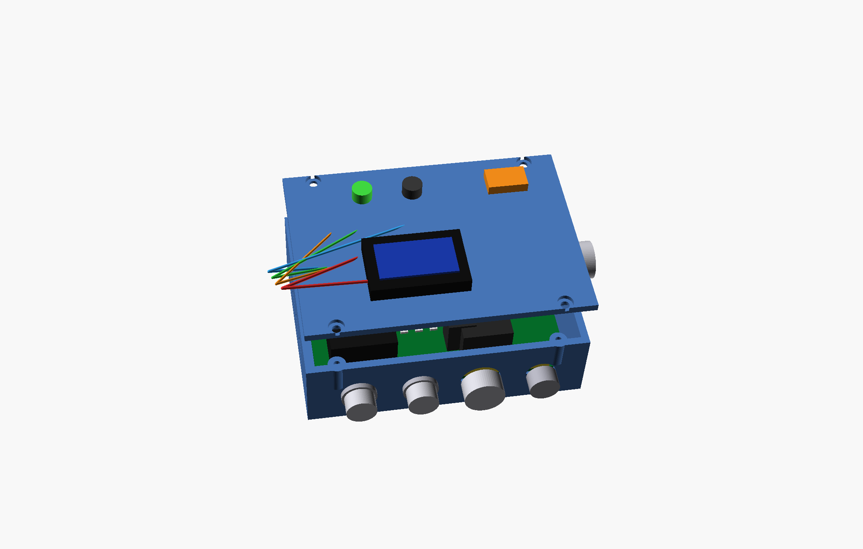
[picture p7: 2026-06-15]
renders/enclosure_lid_off.png

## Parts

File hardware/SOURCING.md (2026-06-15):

# Sourcing & ordering

The board is sourced in two parts: a **Mouser cart** for all the passives, ICs,
connectors, diodes, fuse, buttons and the toroid core; plus three
**off-Mouser modules** (chosen so the board is hand-solderable — no QFN/thermal-pad
reflow) and the magnet wire for the toroid.

Panel RF connectors are listed directly in `BOM.csv` as Mini-UHF only:

- `P_RF_MINIUHF` = **Amphenol RF 172147** (Mini-UHF panel female), qty 2

The board uses `J3`/`J4` as 2-pin wire-off headers, with Mini-UHF bulkheads wired
by short pigtails.

## Panel RF + cable hardware (now included in BOM.csv)

The panel RF bulkheads are not board-mounted footprints; they are enclosure parts
wired by pigtail to `J3`/`J4`.

- `P_RF_MINIUHF` (Mini-UHF panel female) qty 2
- `W_RF_RG316` RG-316 50 ohm coax, qty 1 (1 m default)

Yes: the bulkheads need short coax pigtails. Use RG-316 and keep both pigtails
as short as practical.

Selected connector: Amphenol RF 172147 uses a threaded bushing + nut, so flange
screw holes are not required for the default enclosure build.

There is no dedicated coax board connector footprint for RF on this PCB: J3/J4 are
2-pin terminations (RF signal + GND), so the RG-316 pigtails land directly there.

If your station side is SO-239/PL-259, include Mini-UHF<->UHF adapters (one per
RF port) in your enclosure build kit.

Recommended adapter BOM item:

- `P_RF_ADAPT_UHF` = **Amphenol RF 242132**, qty 2
  (Mini-UHF male to UHF female / SO-239 side)

## Radio cable build materials (now included in BOM.csv)

Added offboard cable-build items for CI-V/CAT harnesses:

- `P_RADIO_GX16_PANEL` qty 1 (panel bulkhead)
- `P_RADIO_GX16_PLUG` qty 3 (one cable-side GX16 per radio cable)
- `W_RADIO_CTRL` qty 1 (shielded multicore control cable)
- `P_CIV_3P5MM` qty 1 (Icom CI-V plug)
- `P_CAT_DB9F` qty 1 (Kenwood CAT termination)
- `P_CAT_MINIDIN8` qty 1 (Yaesu CAT termination)

If your specific radio uses a different CAT connector style, substitute that
termination at cable-build time and keep the GX16 side pinout unchanged.

## Motor connector strategy (detachable, service-friendly)

For the antenna motor output, this build uses a detachable panel connector:

- `P_MOTOR_GX16_PANEL` = GX16-4 panel female bulkhead (enclosure side)
- `P_MOTOR_GX16_PLUG` = GX16-4 cable male plugs
- `W_MOTOR_4C` = 4-core 18-22 AWG cable stock

Use a short internal lead from J6 to the panel bulkhead, then build external
adapter leads from GX16-4 to whatever your antenna expects (Tarheel and other
screwdriver antennas vary by harness/end termination).

### Internal board wiring for this revision

For the current PCB revision, the best mobile-installation practice is:

- use the board holes/headers as **solder points for short internal harnesses**
- anchor those harnesses with **strain relief** inside the enclosure
- avoid loose Dupont-style jumper wires for permanent in-vehicle service

Why: the present board uses generic 2.54 mm header footprints for flexibility,
but friction-only jumper leads are not the best long-term choice in a vibrating
vehicle environment.

### Preferred connector family for a future board revision

If the board is revised specifically for vehicle service, consider replacing the
plain 2.54 mm headers with locking wire-to-board connectors such as:

- **Molex KK 254 with friction lock** for light signal wiring
- **JST-VH** for higher-current power wiring
- **Molex Micro-Fit 3.0** for a more robust locking harness system

Those are recommendations for a future board revision only; the current build is
best handled with direct-soldered internal harnesses.

Why we are **not** standardizing the enclosure-side connector to Tarheel's Molex:

- The Tarheel Molex is an inline cable connector, not a panel bulkhead.
- Keeping GX16-4 on the enclosure preserves a rugged, detachable, generic panel
  interface while still allowing a Tarheel-specific adapter cable in the box.

### Tarheel adapter harness (supported out of the box)

Added BOM items for a Tarheel-compatible adapter lead:

- `P_MOTOR_TARHEEL_KIT` = Tarheel Molex Kit (vendor-supplied inline connector set)
- `W_MOTOR_4C` = 4-conductor cable stock for the Tarheel adapter harness and the
  primary antenna lead

Recommended ordering path:

- Buy the Tarheel Molex kit directly from Tarheel if available for your antenna.
- If ordering equivalent parts elsewhere, verify shell/pin style against your
  exact Tarheel connector before substituting.

## Mouser cart

**Saved cart:** https://www.mouser.com/Tools/SavedCart/Share?AccessID=fe3bac254c

**⚠ Cart corrections (design simplified to a pure auto-tuner — encoder / MODE
switch / memory button / hall sensor removed):**
- **Add** F1 — `1812L300/24SLER` (Littelfuse), Qty 1.
- **Remove** `PEC11R-4220F-S0024` (rotary encoder — gone).
- **Reduce** `PTS645VL58-2LFS` to **2** (SW1 TUNE, SW2 PARK); `61300311121` to **1**
  (J_TUNE only); `RC0805FR-0710KL` 10k to **9**; `RC0805FR-071KL` 1k to **3**;
  `CL21B104KBCNNNC` 100nF to **10**.
- **Set** `61300211121` → 3, `61300411121` → 3.
- Easiest: re-import the regenerated `BOM.csv` instead of hand-editing.

**Subtotal: ≈ $15** _(estimate for single-build qty; confirm in the corrected cart —
the shared-cart page can't be read programmatically.)_

The cart should contain these **25 unique part numbers / 54 pieces** (consolidated
from `BOM.csv`; multiple board designators share one part number). Compare against
the cart to confirm nothing's missing:

| Qty | MPN | Part | Designators |
|----:|-----|---|---|
| 10 | CL21B104KBCNNNC | 100nF 0805 | C3,C5,C6,C11–C15,C_EN,C_INA |
| 7 | RC0805FR-0710KL | 10k 0805 | R7,R8,R_CIV2,R_EN,R_IO12,R_TD,R_TU |
| 6 | RC0805FR-074K7L | 4.7k 0805 | R5,R6,R12,R13,R_CIV1,R_CIV3 |
| 3 | 61300211121 | 1×02 header | J1,J3,J4 |
| 1 | 61300311121 | 1×03 header | J_TUNE |
| 2 | PTS645VL58-2LFS | tactile button | SW1,SW2 |
| 2 | EEE-FK1E101P | 100µF 25V SMD alu | C1,C_VM |
| 2 | CL21B102KBANNNC | 1nF 0805 | C9,C10 |
| 2 | BAT46WS | Schottky SOD-323 | D2,D3 |
| 3 | 61300411121 | 1×04 header | J6,J8,J_OLED |
| 2 | MMBT3904LT1G | NPN SOT-23 | Q1,Q2 |
| 1 | EEE-FK1C470P | 47µF 16V SMD alu | C2 |
| 1 | GRM21BR61C106KE15L | 10µF 0805 | C4 |
| 1 | 08055A3R3CAT2A | 3.3pF 0805 C0G | C7 |
| 1 | CL21C101JBANNNC | 100pF 0805 C0G | C8 |
| 1 | SMBJ13A-E3/52 | TVS | D1 |
| 1 | 1812L300/24SLER | 3A PTC fuse 1812 | F1 |
| 1 | 61300611121 | 1×06 header | J2 |
| 1 | WSL2512R0500FEA | 0.05Ω 1W shunt | R_SH |
| 1 | RC0805FR-07150RL | 150Ω 0805 | R3 |
| 1 | RC0805FR-071KL | 1k 0805 | R4 |
| 1 | 5943000201 | FT37-43 toroid core | T1 |
| 1 | MAX3232ESE+ | RS-232 xcvr SOIC-16 | U3 |
| 1 | INA180A1IDBVR | current-sense amp | U6 |

> Order a few spares of the 0805 passives — they're pennies and easy to lose.

> **Mouser import:** `BOM.csv` has a short **Ref** column (one representative
> designator per part, e.g. `C3` for the eleven 100nF caps) — map that to Mouser's
> *Customer #* (it stays under Mouser's 21-char limit). The full position list for
> each part is in the **Designators** column for assembly.

## Off-Mouser modules & wire

| Ref | Part | Price | Pack | Per unit | Source |
|-----|---|---|---|---|---|
| **U2** | ESP32 DevKit V1 (30-pin) | $19.07 shipped | 1 | **$19.07** | [Amazon B0CNYK7WT2](https://www.amazon.com/dp/B0CNYK7WT2) |
| **U4** | Pololu DRV8871 carrier #2990 | $60.90 (FedEx 2-day) | 10 | **$6.09** | [Pololu #2990](https://www.pololu.com/product/2990) |

**Per-board module cost ≈ $25.16** (1× each, excluding U1 which is now on-Mouser).

Notes:
- U4 comes in a multi-pack — the per-unit cost above assumes you use the whole
  pack across multiple builds. One board needs 1.
- U1 is now the actual board-side regulator: **Murata OKI-78SR-3.3/1.5-W36-C**,
  a fixed-output 3.3 V switching regulator available from Mouser.
- U1 specs used for this revision: **7-36 V input**, **1.5 A max output**, about
  **4.95 W output power**, fixed **3.3 V** output.
- A plain linear regulator is **not recommended** for the full board supply from
  12 V. At only 250 mA load it would burn about `(12 - 3.3) * 0.25 = 2.18 W` as
  heat; at 500 mA it would burn about `4.35 W`, which is not practical in this
  enclosure without serious heatsinking.
- Verify the SIP pin orientation against the silkscreen before soldering U1.

## 3.3 V rail and input power budget

- **Current 3.3 V design target:** about **0.5 A** continuous logic rail budget.
- That corresponds to about **1.65 W** on the 3.3 V rail.
- The 12 V board input path itself is protected by a **3 A PTC**, so the overall
  board input path is in the rough **36 W class** at 12 V, but most of that is for
  the **motor path**, not the logic rail.
- Practical reading: the logic supply is a low-watt rail, while the motor section
  is what drives the higher input current requirement.

**T1 magnet wire:** the toroid *core* (5943000201) is in the Mouser cart; you also
need ~30 turns of **0.3 mm (≈30 AWG) enamelled copper** for the secondary (any
small spool — Amazon, or Remington Industries magnet wire on Mouser). The 1-turn
primary is just the through-line wire passing through the core.

## Cost summary (per board)

| Source | Cost |
|---|---|
| Mouser cart (board parts incl. U1) | **re-import `BOM.csv` to refresh** |
| ESP32 DevKit V1 (U2) | $19.07 |
| Pololu DRV8871 #2990 (U4) | $6.09 |
| Magnet wire (T1 secondary) | ~$1 (spool covers many) |
| **Modules + wire subtotal** | **≈ $26.16** plus the Mouser cart |
| **Grand total per board** | **depends on refreshed Mouser cart** (+ bare PCB ~$2–10) |

_Not included:_ the bare 4-layer PCB (≈$2–10/board from JLCPCB, qty-dependent — see
`fab/tuner_gerbers.zip`), and the panel-mount hardware wired by flying lead (2×
Mini-UHF bulkheads, GX16 radio bulkhead, 12 V jack, the enclosure) — your choice of vendor;
see `RADIO_CONNECTOR.md` and `enclosure/README.md`.

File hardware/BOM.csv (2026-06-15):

Ref | Qty | Value | Footprint | MPN | Designators
C1 | 2 | 100uF_25V | Capacitor_SMD:CP_Elec_6.3x5.4 | EEE-FK1E101P | C1,C_VM
C2 | 1 | 47uF_10V | Capacitor_SMD:CP_Elec_5x5.4 | EEE-FK1C470P | C2
C3 | 10 | 100nF | Capacitor_SMD:C_0805_2012Metric | CL21B104KBCNNNC | C3,C5,C6,C11,C12,C13,C14,C15,C_EN,C_INA
C4 | 1 | 10uF | Capacitor_SMD:C_0805_2012Metric | GRM21BR61C106KE15L | C4
C7 | 1 | 3p3_NP0 | Capacitor_SMD:C_0805_2012Metric | 08055A3R3CAT2A | C7
C8 | 1 | 100pF_NP0 | Capacitor_SMD:C_0805_2012Metric | CL21C101JBANNNC | C8
C9 | 2 | 1nF | Capacitor_SMD:C_0805_2012Metric | CL21B102KBANNNC | C9,C10
D1 | 1 | SMBJ13A | Diode_SMD:D_SMB | SMBJ13A-E3/52 | D1
D2 | 2 | BAT46 | Diode_SMD:D_SOD-323 | BAT46WS | D2,D3
F1 | 1 | 3A_PTC | Fuse:Fuse_1812_4532Metric | 1812L300/24SLER | F1
J1 | 3 | 12V_IN / RF_IN_SO239 / RF_OUT_SO239 | Connector_PinHeader_2.54mm:PinHeader_1x02_P2.54mm_Vertical | 61300211121 | J1,J3,J4
J2 | 1 | RADIO_UNIVERSAL | Connector_PinHeader_2.54mm:PinHeader_1x06_P2.54mm_Vertical | 61300611121 | J2
J6 | 3 | ANT_CTRL / DEBUG_UART / SSD1306 | Connector_PinHeader_2.54mm:PinHeader_1x04_P2.54mm_Vertical | 61300411121 | J6,J8,J_OLED
J_TUNE | 1 | JOG_ROCKER | Connector_PinHeader_2.54mm:PinHeader_1x03_P2.54mm_Vertical | 61300311121 | J_TUNE
Q1 | 2 | MMBT3904 | Package_TO_SOT_SMD:SOT-23 | MMBT3904LT1G | Q1,Q2
R3 | 1 | 150R | Resistor_SMD:R_0805_2012Metric | RC0805FR-07150RL | R3
R4 | 3 | 1k | Resistor_SMD:R_0805_2012Metric | RC0805FR-071KL | R4,R_SA,R_SB
R5 | 6 | 4.7k | Resistor_SMD:R_0805_2012Metric | RC0805FR-074K7L | R5,R6,R12,R13,R_CIV1,R_CIV3
R7 | 9 | 10k | Resistor_SMD:R_0805_2012Metric | RC0805FR-0710KL | R7,R8,R_CIV2,R_EN,R_IO12,R_SA_PU,R_SB_PD,R_TD,R_TU
R_SH | 1 | 0R05_1W | Resistor_SMD:R_2512_6332Metric | WSL2512R0500FEA | R_SH
SW1 | 2 | PARK / TUNE | Connector_PinHeader_2.54mm:PinHeader_1x02_P2.54mm_Vertical | PTS645VL58-2LFS | SW1,SW2
T1 | 1 | FT37-43_1:30 | Tuner:CT_FT37_43_Toroid | 5943000201 | T1
U1 | 1 | OKI78SR_3V3 | Tuner:REG_OKI78SR | OKI-78SR-3.3/1.5-W36-C | U1
U2 | 1 | ESP32-WROOM-32E | Tuner:ESP32_DevKit_30 | ESP32 DevKit V1 30-pin (DOIT/NodeMCU-32S) | U2
U3 | 1 | MAX3232 | Package_SO:SOIC-16_3.9x9.9mm_P1.27mm | MAX3232ESE+ | U3
U4 | 1 | DRV8871_CARRIER | Tuner:DRV8871_CARRIER | POLOLU-2990 | U4
U6 | 1 | INA180A1 | Package_TO_SOT_SMD:SOT-23-5 | INA180A1IDBVR | U6
P_RF_MINIUHF | 2 | RF_BULKHEAD_MINI_UHF_PANEL_F | Panel_Mount:Offboard | Amphenol RF 172147 | PANEL_RF_IN,PANEL_RF_OUT
P_RF_ADAPT_UHF | 2 | ADAPTER_MINIUHF_M_TO_UHF_F | Connector_RF:Offboard | Amphenol RF 242132 | RF_IN_PANEL_ADAPTER,RF_OUT_PANEL_ADAPTER
W_RF_RG316 | 1 | RG316_50OHM_COAX_1M | Wire:Offboard | RG-316 coax cable 1 m | RF_PIGTAIL_IN,RF_PIGTAIL_OUT
P_RADIO_GX16_PANEL | 1 | GX16_PANEL_FEMALE_6PIN | Panel_Mount:Offboard | GX16-6 panel bulkhead female | RADIO_PANEL
P_RADIO_GX16_PLUG | 3 | GX16_CABLE_MALE_6PIN | Panel_Mount:Offboard | GX16-6 cable male plug | RADIO_CABLE_ICOM,RADIO_CABLE_YAESU,RADIO_CABLE_KENWOOD
P_MOTOR_GX16_PANEL | 1 | GX16_PANEL_FEMALE_4PIN | Panel_Mount:Offboard | GX16-4 panel bulkhead female | ANTENNA_PANEL
P_MOTOR_GX16_PLUG | 2 | GX16_CABLE_MALE_4PIN | Panel_Mount:Offboard | GX16-4 cable male plug | ANTENNA_CABLE_PRIMARY,ANTENNA_CABLE_SPARE
P_MOTOR_TARHEEL_KIT | 1 | TARHEEL_MOLEX_4PIN_KIT | Connector_Offboard | Tarheel Molex Kit (4-pin inline pair + pins + heat shrink) | ANTENNA_CABLE_TARHEEL
W_RADIO_CTRL | 1 | SHIELDED_MULTICORE_24-26AWG_3M | Wire:Offboard | Shielded multicore cable 24-26 AWG 3 m | RADIO_CABLE_ICOM,RADIO_CABLE_YAESU,RADIO_CABLE_KENWOOD
W_MOTOR_4C | 1 | MOTOR_CABLE_4C_18-22AWG_2M | Wire:Offboard | 4-conductor stranded cable 18-22 AWG 2 m | ANTENNA_CABLE_PRIMARY
W_MOTOR_4C_TARHEEL | 1 | MOTOR_CABLE_4C_18-22AWG_1M | Wire:Offboard | 4-conductor stranded cable 18-22 AWG 1 m | ANTENNA_CABLE_TARHEEL
P_CIV_3P5MM | 1 | ICOM_CIV_3P5MM_PLUG | Connector_Audio:Offboard | 3.5 mm mono plug solder type | RADIO_CABLE_ICOM
P_CAT_DB9F | 1 | KENWOOD_CAT_DB9F | Connector_DSub:Offboard | DE-9 female solder-cup connector + hood | RADIO_CABLE_KENWOOD
P_CAT_MINIDIN8 | 1 | YAESU_CAT_MINIDIN8 | Connector_DIN:Offboard | Mini-DIN-8 male solder plug | RADIO_CABLE_YAESU

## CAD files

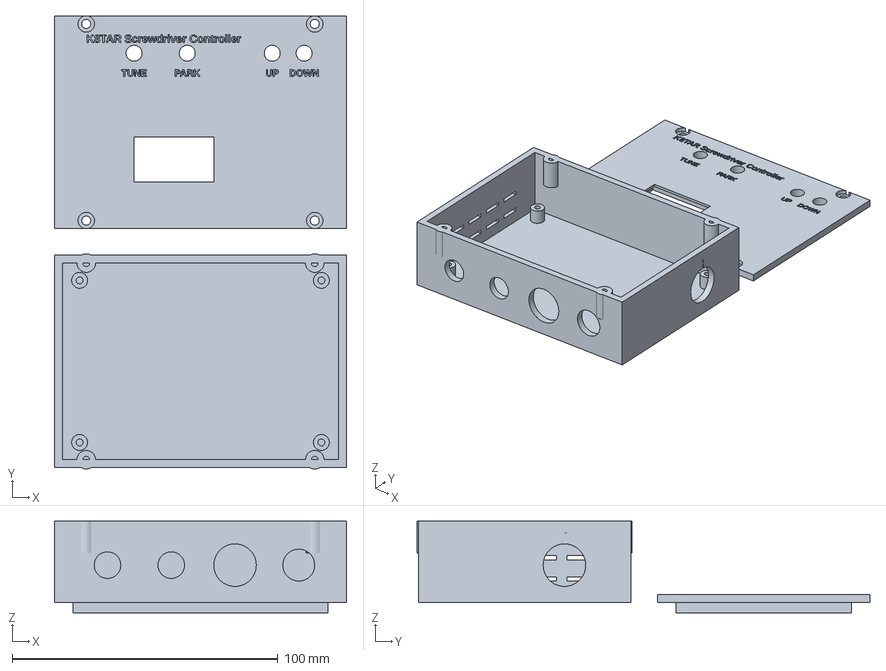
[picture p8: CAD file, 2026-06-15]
hardware/enclosure/enclosure_full.3mf
110.0 x 170.5 x 34.6 mm

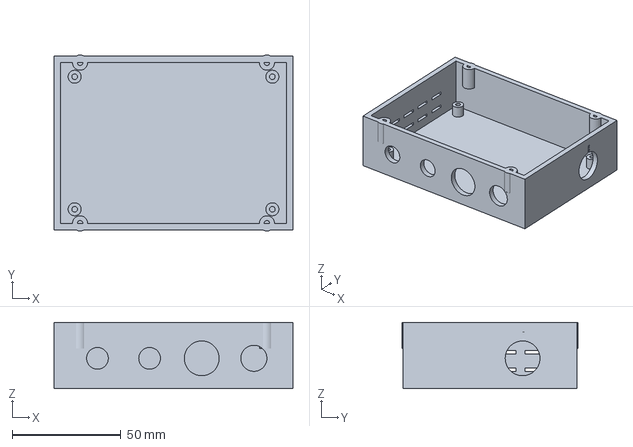
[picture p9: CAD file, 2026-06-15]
hardware/enclosure/base.3mf
110.0 x 81.0 x 30.6 mm

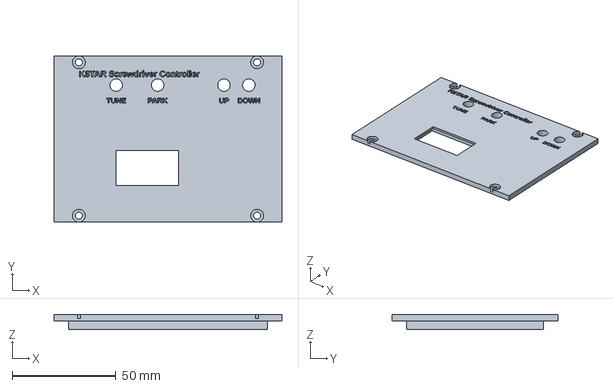
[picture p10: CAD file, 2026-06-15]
hardware/enclosure/lid.3mf
110.0 x 80.0 x 7.00 mm

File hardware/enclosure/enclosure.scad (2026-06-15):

// =============================================================================
//  ESP32 Screwdriver Antenna Tuner — 3D-printed enclosure (parametric)
//  Two parts: base tray (PCB + rear panel connectors) and lid (control panel).
//  Units: mm.  Render one part at a time with the `part` selector below.
//
//  The board is 100 x 70 mm with M3 mounting holes at (4.5,4.5) (95.5,4.5)
//  (4.5,65.5) (95.5,65.5) — these match gen_pcb.py HOLES exactly.
//
//  Cutout positions are derived from the PCB component placement (KiCad coords,
//  origin top-left, Y down).  All are parameters — nudge to match the exact
//  parts you mount.  Print base + lid in PETG (cab heat) or PLA for bench use.
// =============================================================================

part = "both";          // "base" | "lid" | "both" | "assembled" | "assembled_clear" | "lid_off" | "service_open"
view_rot = [0, 0, 0];    // rotate whole preview for render angles
$fn  = 64;

// ---- board & fit ------------------------------------------------------------
board_l   = 100;        // X
board_w   = 70;         // Y
board_t   = 1.6;
gap       = 2;          // clearance board edge -> inner wall
wall      = 3;          // side wall thickness
floor_t   = 3;          // base floor thickness
lid_t     = 3;          // lid plate thickness
standoff_h= 6;          // PCB underside above floor (room for through-hole tails)
comp_clear= 20;         // headroom above board (DevKit on header + OLED ~ tallest)

// ---- derived ----------------------------------------------------------------
inner_l = board_l + 2*gap;          // 104
inner_w = board_w + 2*gap;          // 74
outer_l = inner_l + 2*wall;         // 110
outer_w = inner_w + 2*wall;         // 80
cav_h   = standoff_h + board_t + comp_clear;   // inner cavity height (27.6)
rim_z   = floor_t + cav_h;          // top of walls
board_z = floor_t + standoff_h;     // board underside Z
board_top = board_z + board_t;
show_board_preview = true;

// board(bx,by) -> enclosure(x,y).  Y is kept (KiCad Y-down == our Y from rear).
function be(bx,by) = [wall+gap+bx, wall+gap+by];

holes = [[4.5,4.5],[95.5,4.5],[4.5,65.5],[95.5,65.5]];   // board coords

// ---- enclosure RF connector sizing -----------------------------------------
// Project standard is Mini-UHF bulkheads for compact enclosure footprint.
rf_bulkhead_pn = "Amphenol RF 172147";
rf_bulkhead_d = 10.0;
rf_mount_holes = false;          // 172147 is a threaded bushing + nut style
rf_mount_hole_d = 3.2;           // M3 clearance
rf_mount_hole_pitch = 14.0;      // center-to-center spacing, adjust to hardware

// ---- rear-panel (Y-min wall) connectors: [x_center, diameter] ---------------
// Panel-mount, wired to the board headers by flying leads.
rear_round = [
  [ 20, rf_bulkhead_d],   // RF IN bulkhead (J3)
  [ 44, rf_bulkhead_d],   // RF OUT bulkhead (J4)
  [ 68, 16.0],   // GX16 radio bulkhead (J2 universal)
  [ 92, 12.0],   // 12V power panel jack (J1)
];
rear_z    = floor_t + 11;   // connector centre height above floor
// ---- right side wall (X-max) extras ----------------------------------------
motor_bulkhead_y = 55;
motor_bulkhead_d = 16.0;        // detachable antenna connector (GX16-4 style)

// ---- lid control-panel cutouts (ergonomic layout; enclosure coords) ---------
// PANEL-MOUNTED UI wired by flying lead to the board headers (J_OLED, SW1 TUNE,
// SW2 PARK, J_TUNE UP/DOWN controls. Pure auto-tuner: no encoder, no mode switch.
oled_c    = [45, 26];  oled_win  = [30, 17];   // SSD1306 active-area window
btn_xy    = [[30,66], [50,66]];  btn_d = 6;    // TUNE / PARK buttons
jog_c     = [88, 66];  jog_btn_d = 6;          // UP / DOWN buttons
jog_btn_dx = 6;

// OLED mounting recess (underside): mostly hollow with a thin front lip so the
// module can be glued/taped in from the back.
oled_recess = [40, 28];
oled_front_lip_t = 1.2;

label_depth = 0.6;

module engrave_lid_text() {
  // Title
  translate([12, outer_w - 10, lid_t - label_depth])
    linear_extrude(height=label_depth + 0.05)
      text("K8TAR Screwdriver Controller", size=3.0, font="Liberation Sans:style=Bold", halign="left", valign="baseline");

  // Front control labels
  translate([btn_xy[0][0], btn_xy[0][1]-7.5, lid_t - label_depth])
    linear_extrude(height=label_depth + 0.05)
      text("TUNE", size=2.6, font="Liberation Sans:style=Bold", halign="center", valign="center");
  translate([btn_xy[1][0], btn_xy[1][1]-7.5, lid_t - label_depth])
    linear_extrude(height=label_depth + 0.05)
      text("PARK", size=2.6, font="Liberation Sans:style=Bold", halign="center", valign="center");
  translate([jog_c[0]-jog_btn_dx, jog_c[1]-7.5, lid_t - label_depth])
    linear_extrude(height=label_depth + 0.05)
      text("UP", size=2.6, font="Liberation Sans:style=Bold", halign="center", valign="center");
  translate([jog_c[0]+jog_btn_dx, jog_c[1]-7.5, lid_t - label_depth])
    linear_extrude(height=label_depth + 0.05)
      text("DOWN", size=2.6, font="Liberation Sans:style=Bold", halign="center", valign="center");
}

module engrave_base_text() {
  // Rear connector labels (engraved into outer rear wall).
  for (lbl = [[rear_round[0][0], "RF IN"], [rear_round[1][0], "RF OUT"], [rear_round[2][0], "RADIO"], [rear_round[3][0], "12V"]])
    translate([lbl[0], -0.2, rear_z + 7.2])
      rotate([90, 0, 0])
        linear_extrude(height=0.9)
          text(lbl[1], size=2.2, font="Liberation Sans:style=Bold", halign="center", valign="center");

  // Side connector label (engraved into outer right wall).
  translate([outer_l + 0.2, motor_bulkhead_y, rear_z + 9.0])
    rotate([0, 90, 90])
      linear_extrude(height=0.9)
        text("ANT", size=2.8, font="Liberation Sans:style=Bold", halign="center", valign="center");
}

// =============================================================================

module screw_pilot(d=2.6, h=12) cylinder(d=d, h=h);   // M3 self-tap pilot

// 4 PCB standoffs on the floor; board screwed down from above
module standoffs() {
  for (h = holes) {
    p = be(h[0], h[1]);
    translate([p[0], p[1], floor_t]) difference() {
      cylinder(d=6, h=standoff_h);
      translate([0,0,-0.1]) screw_pilot(2.6, standoff_h+0.2);
    }
  }
}

// 4 lid-screw bosses hanging from the top of the walls (above the board, so the
// board can still drop in).  Lid screws down into these.
lid_boss = [[12, wall], [outer_l-12, wall],
            [12, outer_w-wall], [outer_l-12, outer_w-wall]];
module lid_bosses() {
  for (b = lid_boss)
    translate([b[0], b[1], rim_z-12]) difference() {
      cylinder(d=7, h=12);
      translate([0,0,2]) screw_pilot(2.6, 11);
    }
}

module base() {
  difference() {
    union() {
      // hollow shell (open top)
      difference() {
        cube([outer_l, outer_w, rim_z]);
        translate([wall, wall, floor_t]) cube([inner_l, inner_w, cav_h+1]);
      }
      standoffs();
      lid_bosses();
    }
    // rear-wall round cutouts (bored along +Y through the Y-min wall)
    for (c = rear_round)
      translate([c[0], -1, rear_z]) rotate([-90,0,0]) cylinder(d=c[1], h=wall+2);
    // optional flange screw holes for RF bulkheads (first two rear cutouts)
    if (rf_mount_holes) {
      for (cx = [rear_round[0][0], rear_round[1][0]]) {
        for (sx = [-1, 1])
          translate([cx + sx*(rf_mount_hole_pitch/2), -1, rear_z])
            rotate([-90,0,0]) cylinder(d=rf_mount_hole_d, h=wall+2);
      }
    }
    // detachable antenna connector hole on side wall (J6 harness)
    translate([outer_l-wall-1, motor_bulkhead_y, rear_z]) rotate([0,90,0]) cylinder(d=motor_bulkhead_d, h=wall+2);
    // vent slots on the left (X-min) side wall
    for (sy = [20:12:60]) for (sz = [0,1])
      translate([-1, sy, floor_t+5+sz*8]) cube([wall+2, 8, 1.6]);

    engrave_base_text();
  }
}

module lid() {
  difference() {
    union() {
      cube([outer_l, outer_w, lid_t]);
      // locating lip that drops into the cavity (inset to clear lid bosses)
      translate([wall+4, wall+4, -4])
        cube([inner_l-8, inner_w-8, 4]);
    }
    // lid screw clearance holes + counterbores
    for (b = lid_boss) translate([b[0], b[1], -0.1]) {
      cylinder(d=3.4, h=lid_t+4.2);
      translate([0,0,lid_t-1.6]) cylinder(d=6.2, h=2);
    }
    // ---- control-panel cutouts ----
    // OLED active-area window.
    translate([oled_c[0]-oled_win[0]/2, oled_c[1]-oled_win[1]/2, -1])
      cube([oled_win[0], oled_win[1], lid_t+2]);
    // OLED module recess from the back side; leaves a thin lip at the front.
    translate([oled_c[0]-oled_recess[0]/2, oled_c[1]-oled_recess[1]/2, -4.1])
      cube([oled_recess[0], oled_recess[1], lid_t + 4.2 - oled_front_lip_t]);
    // Buttons pass straight through the lid/lip for back-side glue mounting.
    for (b = btn_xy) translate([b[0], b[1], -4.1]) cylinder(d=btn_d, h=7.3);
    // Jog rocker opening passes fully through for back-side mounting.
    for (sx = [-jog_btn_dx, jog_btn_dx])
      translate([jog_c[0]+sx, jog_c[1], -4.1]) cylinder(d=jog_btn_d, h=7.3);
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

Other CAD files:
hardware/enclosure/base.stl
hardware/enclosure/enclosure_full.stl
hardware/enclosure/lid.stl

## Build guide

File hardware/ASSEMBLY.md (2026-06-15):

# Assembly Guide — ESP32 Screwdriver Antenna Tuner

A step-by-step build for the tuner PCB. The board is **mixed-technology**: mostly
hand-solderable 0805 SMD passives + a few SMD ICs, then through-hole headers, a
hand-wound toroid, and three socketed modules. Work **lowest-profile parts first**
so nothing blocks your iron later, and **test between the major stages** so a fault
is easy to localize.

- **Skill:** basic SMD soldering (0805, SOT-23, SOIC). Everything was chosen to be
  hand-solderable — no leadless/QFN, no thermal pads (those live on the modules).
- **Time:** ~2–4 hours for the board, plus winding T1 and panel wiring.
- **References:** `BOM.csv` (the **Ref** column = the tag on each part; the
  **Designators** column lists every position it populates), `renders/pcb_routed_top.png`
  (placement), `SOURCING.md` (where to buy), `RADIO_CONNECTOR.md` + `enclosure/README.md`
  (panel wiring), `firmware/FIRMWARE_SPEC.md` (bring-up).

---

## Tools & supplies

- Fine-tip soldering iron (~0.4 mm) **or** hot-air/hotplate + solder paste.
- Thin solder (0.5 mm), **flux** (essential for SMD), solder wick, IPA + brush.
- Fine tweezers, magnification (loupe/microscope helps for 0805).
- Multimeter (continuity + voltage). **Bench PSU with current limit** for first power-up.
- 0.3 mm (≈30 AWG) enamelled wire for T1; a short length of stiff hookup wire for
  the T1 primary; 2.54 mm header strip + Dupont/ribbon for panel wiring.

> **ESD:** the ESP32, MAX3232, INA180 and DRV8871 are static-sensitive — use a
> grounded mat/strap, especially in dry/winter conditions.

---

## Orientation

Hold the board with the silkscreen readable. Landmarks (top copper render):
**U2 (ESP32) down the left edge · connectors (J3 J4 J1 J6 J8) along the top ·
U1 buck top-center · U4 motor carrier center · T1 toroid + detectors center-right ·
U3 (MAX3232) right · the UI header row (J_OLED SW1 SW2 J_TUNE) along
the bottom · 4× M3 mounting holes at the corners.**

Every part's reference designator is on the silkscreen. Pin-1 / polarity marks are
on silk too — match them exactly for the polarized parts flagged below.

---

## Stage 1 — SMD passives (flattest first, non-polarized)

These don't care about orientation, but 0805 R/C are **unmarked** — keep each value
in its own labeled dish and do one value at a time.

**1a. Resistors (0805):**
| Ref | Qty | Value | Positions |
|-----|----:|---|---|
| R3 | 1 | 150 Ω | R3 |
| R4 | 3 | 1 kΩ | R4,R_SA,R_SB |
| R5 | 6 | 4.7 kΩ | R5,R6,R12,R13,R_CIV1,R_CIV3 |
| R7 | 9 | 10 kΩ | R7,R8,R_CIV2,R_EN,R_IO12,R_TD,R_TU,R_SA_PU,R_SB_PD |

**1b. MLCC capacitors (0805):**
| Ref | Qty | Value | Positions |
|-----|----:|---|---|
| C3 | 10 | 100 nF | C3,C5,C6,C11,C12,C13,C14,C15,C_EN,C_INA |
| C4 | 1 | 10 µF | C4 |
| C7 | 1 | 3.3 pF | C7 |
| C8 | 1 | 100 pF | C8 |
| C9 | 2 | 1 nF | C9,C10 |

**Technique (hand):** flux a pad, tin it, tack one end of the part, then solder the
other end and re-flow the first. **Technique (paste):** paste + place all, then
hot-air or hotplate reflow this whole stage at once.

✅ *Check:* every R/C value landed on the right designators (compare to the table).

---

## Stage 2 — SMD semiconductors & power SMD (orientation matters)

**2a. Non-polarized but distinct packages:**
| Ref | Part | Package | Note |
|-----|---|---|---|
| R_SH | WSL2512R0500FEA | 2512 | 0.05 Ω shunt — lots of heat, flood the pads |
| F1 | 1812L300/24SLER | 1812 | resettable fuse |

**2b. Diodes — match the cathode band to the silkscreen mark:**
| Ref | Part | Package | Orientation |
|-----|---|---|---|
| D1 | SMBJ13A-E3/52 (TVS) | SMB | **unidirectional** — band (cathode) to the `+12V` side per silk |
| D2,D3 | BAT46WS (Schottky) | SOD-323 | band (cathode) to the silk cathode line |

**2c. Transistors / ICs — match pin 1 (dot/notch) to the silk pin-1 mark:**
| Ref | Part | Package |
|-----|---|---|
| Q1,Q2 | MMBT3904LT1G | SOT-23 |
| U6 | INA180A1IDBVR | SOT-23-5 |
| U3 | MAX3232ESE+ | SOIC-16 (pin-1 dimple toward the silk dot) |

> SOIC tip: tack two opposite corners first, check it's seated square, then drag-
> solder each side with plenty of flux; wick any bridges.

✅ *Check:* D1/D2/D3 band direction; Q/U pin-1; no SOIC bridges (inspect under light).

---

## Stage 3 — SMD electrolytics (tallest SMD — **polarized**)

| Ref | Qty | Value | Positions |
|-----|----:|---|---|
| C1 | 2 | 100 µF 25 V | C1, C_VM |
| C2 | 1 | 47 µF 16 V | C2 |

**Polarity:** these are SMD aluminium cans — the bevelled/marked corner is the
**negative** terminal. Match it to the silkscreen polarity (the `-` / unfilled pad;
`+` is the square/striped pad). Getting this wrong = bulged cap on power-up.

✅ *Check:* all three caps' polarity against silk. This finishes the SMD side —
clean off flux with IPA and inspect the whole board before going through-hole.

---

## Stage 4 — Through-hole: headers and module sockets

The UI controls and most connectors are **2.54 mm headers** (the actual switches,
OLED and Mini-UHF bulkheads are panel-mounted and wired to these — Stage 7).

**4a. Board headers** — solder vertical 2.54 mm headers at every position below.
Use **female** sockets if you want the panel controls to plug in, or male pins to
solder flying leads to:
| Positions | Pins | Function |
|---|---|---|
| J1,J3,J4 | 1×02 | power in / RF in / RF out |
| J2 | 1×06 | universal radio (→ panel GX16) |
| J6,J8,J_OLED | 1×04 | antenna I/O / debug UART / OLED |
| J_TUNE | 1×03 | jog rocker |
| SW1, SW2 | 1×02 | TUNE / PARK buttons |

> The BOM lists the **panel parts** (PTS645 buttons) as the MPNs for SW1/SW2, since
> those mount on the enclosure. You still need plain 2.54 mm header strip for the
> *board* side of those positions — grab a 40-pin strip.
> *(Pure auto-tuner: the rotary encoder, MODE switch and hall connector are gone.)*

### Vehicle-grade note for this revision

For a mobile installation, do **not** rely on loose Dupont-style jumper leads as
the final internal wiring method. Vehicle vibration can work friction-only jumper
connections loose over time.

Recommended approach for this PCB revision:

- For **J1, J2, J3, J4, and J6**, solder the internal harness wires directly into
   the board holes instead of using loose plug-on jumpers.
- Put the **detachable interface at the panel connector** (GX16, Mini-UHF, power
   jack), not at the board header.
- Add **strain relief** close to the PCB using a tie-down, adhesive mount, lacing,
   silicone, or similar support so the solder joints do not carry cable flex.
- Twist the appropriate signal/return pairs and keep them anchored so they cannot
   vibrate against the board or enclosure.

For this revision, the only places where removable board-side connections still
make sense are the socketed modules **U1**, **U2**, and **U4**, plus any lid-side
controls if you specifically want service-open access.

If you plan a future board respin for harsher mobile service, replace the plain
2.54 mm board headers with **locking wire-to-board connectors** rather than loose
friction headers.

**4b. Module sockets:** solder **female header strip** into the U1, U2, U4 module
footprints so the modules are removable (recommended over soldering modules
directly). Match the socket rows to the module footprints exactly.

✅ *Check:* headers sit square (tack one pin, straighten, then solder the rest);
no solder in the module socket holes you'll plug into.

---

## Stage 5 — Wind & install T1 (SWR coupler)

T1 is a 1 : 30, centre-tapped current transformer on a **Fair-Rite 5943000201
(FT37-43)** core. Five pads: **P1, P2** = 1-turn primary (the RF through-line);
**S1, SCT, S2** = the ~30-turn centre-tapped secondary.

1. **Secondary:** wind **30 turns** of 0.3 mm enamelled wire evenly around the core.
   At the **15th turn**, pull out a small twisted loop and leave it as the
   **centre-tap (SCT)** lead. Winding start = **S1**, the loop = **SCT**, the
   end (turn 30) = **S2**. *(Confirm turns/tap against the schematic if in doubt.)*
2. Scrape/tin the enamel off all three secondary leads.
3. **Primary:** pass a single length of stiff hookup wire **once** through the core's
   centre — that one pass = the 1-turn primary. Its two ends go to **P1** and **P2**.
4. Insert all leads into their pads (S1/SCT/S2 + the primary into P1/P2) and solder.
   The primary carries full TX current — use a decent-gauge wire and good joints.

✅ *Check:* secondary leads in the right pads (S1/SCT/S2), primary is one clean turn,
no enamel left on tinned ends.

---

## Stage 6 — Configure & fit the modules (no heat — plug-in)

**Do U1 first and confirm its orientation BEFORE it powers the logic.**

1. **U1 (Murata OKI-78SR-3.3/1.5-W36-C):** this is a **fixed-output 3.3 V SIP
   regulator**, so there is no trimpot to adjust. Verify the pin orientation before
   fitting: **pin 1 = VIN**, **pin 2 = GND**, **pin 3 = VOUT**. Fit it to the U1
   footprint so 12 V enters VIN and 3.3 V leaves VOUT.
2. **U4 (Pololu DRV8871 #2990):** orient VIN/GND/IN1/IN2/OUT1/OUT2 to the silk and
   seat it.
3. **U2 (ESP32 DevKit):** orient so the silk pin names (3V3, GND, D15 …) line up
   (USB end toward the board edge for cable access) and seat it.

✅ *Check:* every module's pin order matches its socket; nothing offset by a row.

---

## Stage 7 — Panel components & wiring (in the enclosure)

Mount the panel parts on the printed enclosure and wire each to its board header
with short flying leads (see `enclosure/README.md` for the cutout layout and
`RADIO_CONNECTOR.md` for the radio connector):

- **OLED** → J_OLED · **TUNE button** → SW1 · **PARK button** → SW2 ·
  **jog rocker** → J_TUNE.
- **Radio:** panel **GX16** → J2 (universal — see RADIO_CONNECTOR.md pinout).
- **RF:** 2× **Mini-UHF bulkhead** → J3 (in) / J4 (out). Keep these leads **short**; the J3→T1
  primary→J4 path carries TX power.
- **Power:** 12 V panel jack → J1.
- **Antenna:** J6 → **GX16-4 panel bulkhead** (motor + optional sensor pair).

> Twist signal/return pairs; keep the RF and motor leads away from the SWR detector
> and ADC wiring.

> For in-vehicle use, treat those board connections as **direct-solder harness
> terminations with strain relief**, not as loose internal jumper leads.

> Board-side RF connection is via the 2-pin headers/pads at J3 and J4 (signal +
> ground), not a dedicated coax board jack. Use short RG-316 pigtails from each
> Mini-UHF bulkhead: center conductor to RF signal pin, shield to GND pin.

### RF pigtail wiring diagram (Mini-UHF panel bulkheads)

```mermaid
flowchart LR
   RFIN[Mini-UHF RF IN bulkhead]
   RFOUT[Mini-UHF RF OUT bulkhead]
   J3[J3 on PCB]
   J4[J4 on PCB]

   RFIN -- center conductor --> J3SIG[RF_IN signal pin]
   RFIN -- shield braid --> J3GND[J3 ground pin]

   RFOUT -- center conductor --> J4SIG[RF_OUT signal pin]
   RFOUT -- shield braid --> J4GND[J4 ground pin]

   J3SIG --> T1[T1 primary through-line]
   T1 --> J4SIG
```

Keep each RG-316 run as short as practical and avoid tight bends at the board edge.

> If your station cabling is SO-239/PL-259, use compact Mini-UHF<->UHF adapters at
> the panel connectors.

> For antenna compatibility (Tarheel and others), make external adapter leads from
> GX16-4 to the antenna's expected motor plug/termination, keeping the panel-side
> interface consistent and detachable.

### Tarheel adapter harness (GX16-4 -> Tarheel 4-pin Molex)

Tarheel antennas commonly use a 4-pin inline Molex-style connector with:

- Pin 1 = Black = motor
- Pin 2 = Red = motor
- Pin 3 = Green = sensor
- Pin 4 = White = sensor

This tuner revision supports the **sensor pair** as an optional pulse-feedback
input. It assumes the green/white pair behaves like a dry contact or open-collector
pulse source. If no valid pulses appear, firmware falls back to stall-only tuning.

Build the adapter lead as:

- GX16-4 pin 1 -> Tarheel pin 1 (black motor)
- GX16-4 pin 2 -> Tarheel pin 2 (red motor)
- GX16-4 pin 3 -> Tarheel pin 3 (green sensor)
- GX16-4 pin 4 -> Tarheel pin 4 (white sensor)

If jog direction is reversed in practice, swap the two motor wires.

```mermaid
flowchart LR
   J6[J6 / GX16-4 panel side]
   TH[Tarheel 4-pin Molex]

   J6P1[Pin 1 motor] --> THP1[Pin 1 black motor]
   J6P2[Pin 2 motor] --> THP2[Pin 2 red motor]
   J6P3[Pin 3 sensor A] --> THP3[Pin 3 green sensor]
   J6P4[Pin 4 sensor B] --> THP4[Pin 4 white sensor]
```

Use the Tarheel Molex kit shell/pins plus a short 4-conductor adapter cable. Run
`PARK` once after installation so the firmware can establish a zero reference,
then later tune sweeps can use the pulse feedback for more repeatable returns.

---

## Stage 8 — Inspection & power-on test

1. **Visual:** re-check every polarized part (D1/D2/D3 bands, C1/C2/C_VM polarity),
   pin-1 on Q/U, module orientation, and scan for bridges/cold joints.
2. **Continuity (power off):** `+12V`↔`GND` **not** shorted; `+3V3`↔`GND` **not**
   shorted.
3. **First power:** bench PSU at **12 V, current limit ~0.3–0.5 A**. It should draw
   little and **not get hot**. Measure **`+3V3` = 3.3 V** at U1 output. If current
   slams to the limit or anything heats — power off, find the short.
4. **Logic alive:** the ESP32 should boot (onboard LED / USB-serial console on the
   debug UART, J8 / GPIO1-3).
5. **Flash firmware** (`firmware/FIRMWARE_SPEC.md`), then verify: OLED draws,
   TUNE/PARK and jog UP/DOWN respond, motor jogs (motor connected, in-line fuse),
   SWR reads with RF applied.

---

## Stage 9 — Calibration & first tune

- **SWR cal:** with a 50 Ω dummy load (= SWR 1.0) and a known mismatch, run the
  firmware's SWR calibration to fit the detector curve (stored in NVS).
- **Motor:** set the stall-current threshold and verify stall-end-stop detection
   for PARK (downward travel) and sweep reversal during TUNE.
- **Radio:** let auto-detect identify your rig (CI-V / Kenwood / Yaesu); confirm
  frequency reads correctly.
- Do a live **TUNE** into the antenna at low power and verify final status/SWR on
   the OLED.

---

## Polarity / pin-1 cheat-sheet

| Part | Watch |
|---|---|
| D1 SMBJ13A | cathode band → `+12V` side |
| D2,D3 BAT46WS | cathode band → silk cathode |
| C1,C2,C_VM | SMD alu: marked/bevelled corner = **negative** |
| Q1,Q2 / U6 / U3 | pin-1 dot/notch → silk pin-1 |
| U1 / U2 / U4 modules | IN/OUT / pin-name order → silk |
| T1 | S1/SCT/S2 secondary, P1/P2 primary (1 turn) |

## Troubleshooting

- **No 3.3 V / high current:** short on `+3V3` or `+12V`, a backwards electrolytic,
  or U1 mis-set/mis-oriented. Re-check Stage 3 & 6.
- **ESP32 won't boot:** U1 output wrong, U2 mis-seated, or GPIO12 held high (it's a
  boot strap — leave it). 
- **OLED blank:** address/orientation of the OLED module, or J_OLED wiring (SDA=GPIO4,
  SCL=GPIO5).
- **SWR reads garbage:** detector polarity (D2/D3), T1 winding/leads, or needs cal.
- **Motor runs one way only / not at all:** U4 IN1/IN2 wiring, or motor leads on J6.
- **No CAT/CI-V:** wrong cable wiring (RADIO_CONNECTOR.md), or CI-V invert flag in
  firmware (flip it), or baud — let auto-detect run.

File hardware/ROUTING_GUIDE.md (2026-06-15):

# ESP32 Screwdriver Antenna Tuner — PCB Routing Guide

Board: `kicad/tuner.kicad_pcb` — 100 × 70 mm, 4-layer, generic hand-solderable rules.
This guide covers the layer stackup, net priorities/trace widths, grounding,
the RF/SWR section, and the Freerouting workflow.

---

## 1. Layer stackup (4-layer)

| Layer | Use |
|---|-----|
| **F.Cu** (top) | Signal + component pads. Short signal routes, RF/SWR. |
| **In1.Cu** | **Solid GND plane** — keep unbroken under the ESP32, RF coupler, and MCU signals. |
| **In2.Cu** | **Power plane** — pour `+3V3`; route `+12V` / motor as wide fills or fat traces here. |
| **B.Cu** (bottom) | Signal + a secondary GND pour. Cross-unders, power, slower signals. |

Inner ground (In1) is already poured as a `GND` zone; bottom has a `GND` pour too.
The most important rule: **don't slot the In1 ground plane** under the RF coupler
or the ESP32 — keep return paths continuous.

---

## 2. Net classes & trace widths

Set these in **Board Setup → Net Classes** before routing (Freerouting reads them).

| Net class | Nets | Track width | Clearance | Notes |
|---|---|---|---|---|
| **Power_12V** | `+12V`, `MTR_OUT1`, `MTR_OUT2`, `MTR_SNS` | **1.0–1.5 mm** | 0.3 mm | Motor current (up to ~3 A). Wide, short, on In2/bottom. |
| **Power_3V3** | `+3V3` | **0.6 mm** | 0.25 mm | Logic rail. Pour on In2 where possible. |
| **Default** | all signals (I²C, UART, SWR, GPIO, CI-V) | 0.3 mm | 0.25 mm | Hand-solderable generic. |
| **RF** | `RF_LINE_IN`, `RF_LINE_OUT` | 0.6–0.8 mm | 0.3 mm | Keep short; see §4. |

Vias: 0.8 mm pad / 0.4 mm drill (already the default). Use plenty to stitch GND.

---

## 3. Grounding strategy

- **One continuous ground** (In1 plane) is the reference for everything. Avoid
  cuts; if you must cross a plane gap with a signal, don't — reroute.
- **Star the high-current return**: the motor return goes carrier-GND →
  `MTR_SNS` → shunt `R_SH` → board GND at a **single point** near the shunt. Do
  NOT let motor return current share copper with the INA180 input or the MCU
  analog grounds — that's what the shunt + single-point tie is for.
- **Stitch** the top/bottom GND pours to In1 with vias every ~5–10 mm, especially
  a ring of vias around the RF coupler and under the ESP32.
- Keep the **buck (U1) input loop** (12V → U1 → GND) tight; put C1 close to U1 IN.

---

## 4. RF / SWR section (the part that needs care)

The Bruene bridge measures forward/reflected power, so its layout affects accuracy.

- **Through-line first.** `RF_LINE_IN` (J3) → **T1 primary (1 turn)** → `RF_LINE_OUT`
  (J4) is the main RF path carrying full TX power. Route it as a **short, wide,
  direct** trace (0.6–0.8 mm) on the top layer with solid ground beneath. This is
  the "1 turn" through the toroid — physically the wire passes through T1's core.
- **Keep the secondary tiny.** T1 `S1/SCT/S2` to the burden `R3`, divider
  `C7/C8/R4`, and detectors `D2/D3` should be a **compact cluster right at T1** —
  short leads keep the sample clean and the bridge balanced.
- **Symmetry matters.** Route `FWD_AC` (D2) and `REV_AC` (D3) paths as
  symmetrically as possible — equal lengths — so forward/reflected track each other.
- `SWR_FWD` / `SWR_REV` are slow DC after the detectors; route them quietly to the
  ESP32 ADC (GPIO34/35), away from the motor/buck switching nodes.
- RF connectors are **flying leads**: J3/J4 are pads where you solder short coax
  pigtails to panel Mini-UHF bulkheads. Keep those pads near the board edge.

> Calibration: the CT turns ratio, C7/C8 divider, and R3 burden are bench-tuned
> for a 50 Ω null. The layout just needs to be short and symmetric.

---

## 5. Placement notes (already done, refine as you route)

- ESP32 DevKit stands **upright (tall) on the left edge** (socketed on female headers).
- Rear edge = connectors (power, antenna motor/sensor, debug, and the
  **universal radio header J2** → panel bulkhead, see `RADIO_CONNECTOR.md`).
- Front edge = UI (OLED, encoder, TUNE/MEM buttons, MODE, jog rocker).
- Buck (U1), motor carrier (U4), MAX3232 (U3) are **socketed modules** — leave
  clearance for the daughterboards and their headers.
- A handful of courtyard overlaps remain in the dense SWR/motor clusters; nudge
  parts apart as you route (this is normal final-placement work).

---

## 6. Freerouting workflow (autorouting) — DONE, reproducible

The board is **already autorouted** (Freerouting 2.2.4): 0 unrouted nets,
469 track segments + 56 vias, 0 electrical DRC errors. To re-route after edits:

```
# from the project root (tuner/).  Freerouting 2.2.4 needs Java 25.
flatpak run --command=python3 org.kicad.KiCad scripts/export_dsn.py     # board -> tuner.dsn
java -jar freerouting.jar -de hardware/kicad/tuner.dsn \
     -do hardware/kicad/tuner.ses -mp 30                                # route (headless)
flatpak run --command=python3 org.kicad.KiCad scripts/import_ses.py     # .ses -> board, refill zones
```

`import_ses.py` calls `pcbnew.ImportSpecctraSES` + `ZONE_FILLER` and saves.
Re-run `scripts/gen_gerbers.py` afterwards to refresh the fab package.

> Prefer hand-routing or want to pre-place critical nets? Lock the RF through-line
> and motor-power tracks first, then autoroute the rest. Order: RF through-line →
> motor power → 3V3/12V → I²C/UART → remaining GPIO.

---

## 7. Before you order

- Run **DRC** to zero (placement overlaps + clearance).
- **Verify the three module footprints** against the real parts you buy
  (ESP32 DevKit row pitch, MP1584 pad pitch, DRV8871 carrier pinout) — these are
  documented-but-approximate and flagged on each footprint's silkscreen.
- Export **Gerbers + drill**:
  `flatpak run --command=kicad-cli org.kicad.KiCad pcb export gerbers tuner.kicad_pcb -o gerbers/`
  `flatpak run --command=kicad-cli org.kicad.KiCad pcb export drill tuner.kicad_pcb -o gerbers/`
- Generic 4-layer, 0.3 mm/0.25 mm rules are within every cheap fab's process.

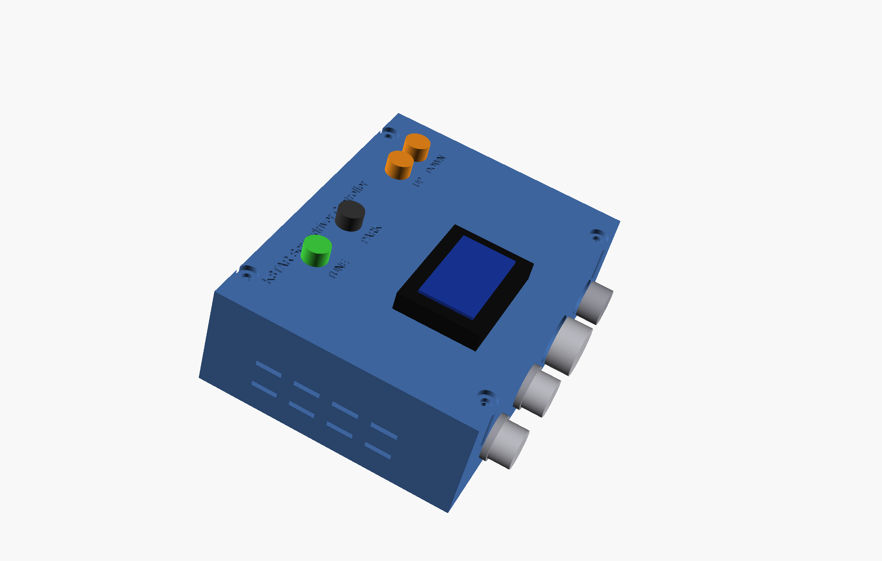
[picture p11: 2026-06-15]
renders/enclosure_assembled_side.png

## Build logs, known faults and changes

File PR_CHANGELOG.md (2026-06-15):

# PR Changelog

## Summary

This update revises the hardware power stage, removes the unused external SWR jack,
refreshes generated board and fab artifacts, and aligns the firmware, documentation,
and enclosure previews with the current mobile-installation design.

## Hardware

- Replaced the adjustable U1 MP1584 module with the fixed-output Murata OKI-78SR-3.3/1.5-W36-C.
- Added a new custom SIP footprint for the Murata regulator.
- Removed the external SWR jack footprint and related board wiring.
- Tightened the U1 placement cluster for a cleaner input-protection-to-regulator layout.
- Softened the T1 toroid silkscreen and moved C7 away from the toroid outline for readability.

## Firmware

- Added power-on self test screens and serial diagnostics.
- Added OLED status improvements: PARK state and TUNED flash sequence.
- Added two live diagnostics pages toggled by a TUNE+PARK hold.
- Added optional Tarheel sensor feedback handling with pulse-based position tracking after PARK homing.

## Mechanical and enclosure

- Updated enclosure previews to reflect the current board revision.
- Removed the external SWR side-wall feature from the enclosure model and docs.
- Kept the GX16-4 antenna connector strategy and service-open render views.

## Documentation

- Reworked the top-level README into a real project overview.
- Updated assembly and sourcing docs for:
  - Murata regulator usage
  - no external SWR jack
  - direct-solder, strain-relieved in-vehicle internal wiring
  - future locking-connector guidance for a board respin
- Updated the BOM and routing notes to match the current board.

## Generated artifacts

- Regenerated schematic, PCB, netlist, DSN, BOM, renders, PDFs, Gerbers, and fab ZIP.
- Removed the obsolete BUCK_MP1584 custom footprint from the tracked KiCad library.
- Added the new REG_OKI78SR custom footprint.

## Validation

- PlatformIO firmware build completed successfully.
- KiCad regeneration completed successfully.
- Gerbers and `fab/tuner_gerbers.zip` were regenerated.

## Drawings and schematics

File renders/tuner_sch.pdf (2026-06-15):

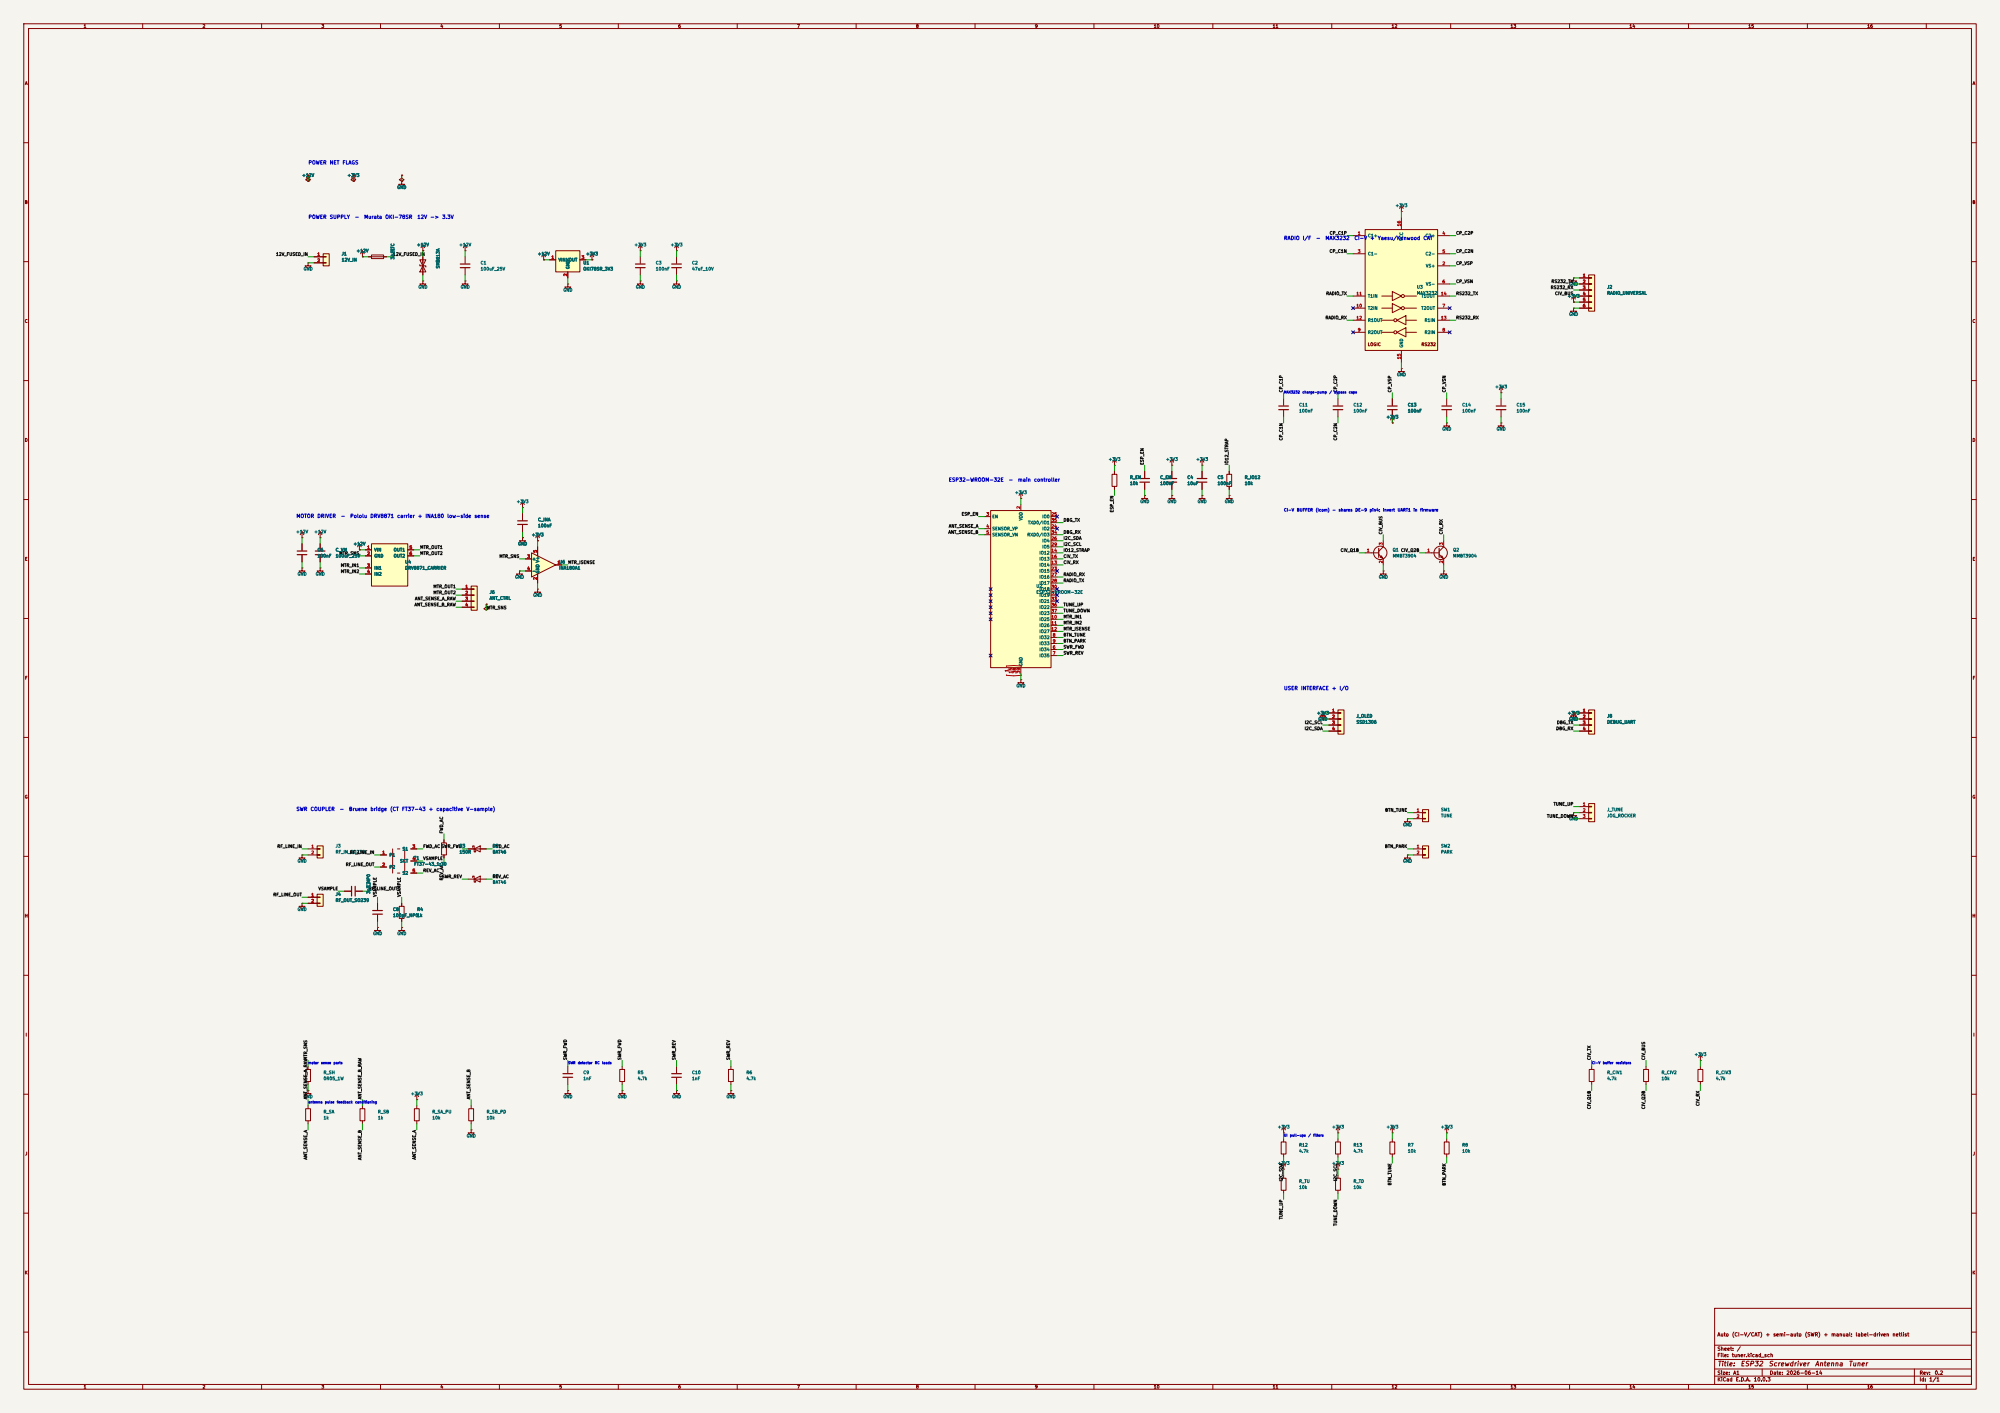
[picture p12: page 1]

MAX3232 charge-pump / bypass caps POWER SUPPLY - Murata OKI-78SR 12V -> 3.3V

RADIO I/F - MAX3232 CI-V + Yaesu/Kenwood CAT

CI-V BUFFER (Icom) - shares DE-9 pin4; invert UART1 in firmware USER INTERFACE + I/O

MOTOR DRIVER - Pololu DRV8871 carrier + INA180 low-side sense SWR COUPLER - Bruene bridge (CT FT37-43 + capacitive V-sample)

Auto (CI-V/CAT) + semi-auto (SWR) + manual; label-driven netlist

Sheet: /
File: tuner.kicad_sch
Title: ESP32 Screwdriver Antenna Tuner

Size: A1 | Rev: 0.2
KiCad E.D.A. 10.0.3 | Id: 1/1

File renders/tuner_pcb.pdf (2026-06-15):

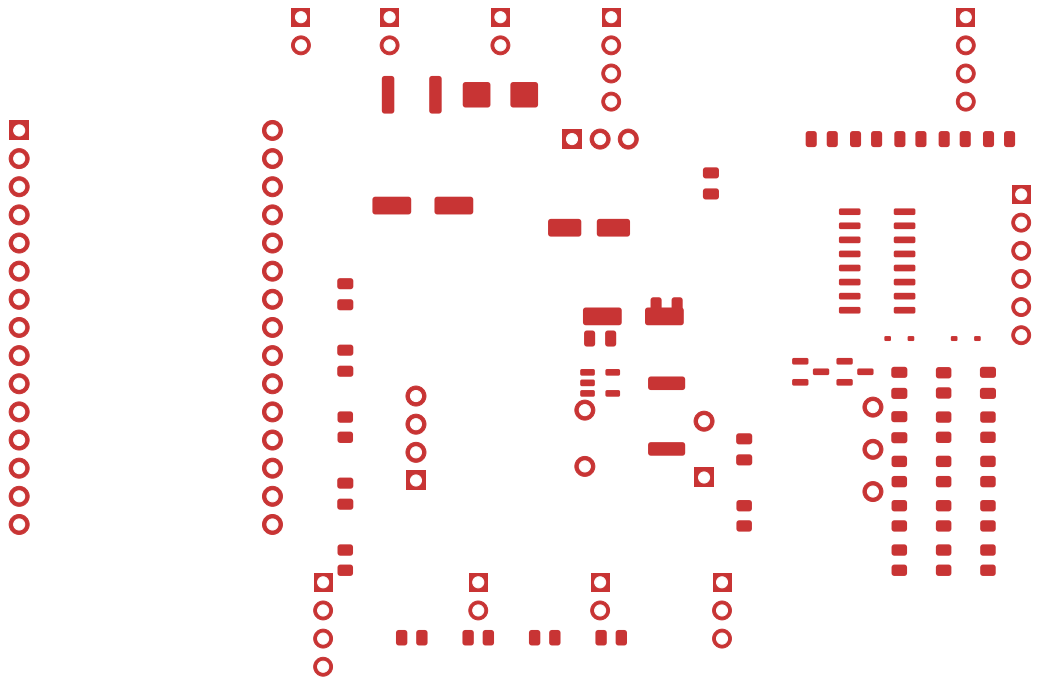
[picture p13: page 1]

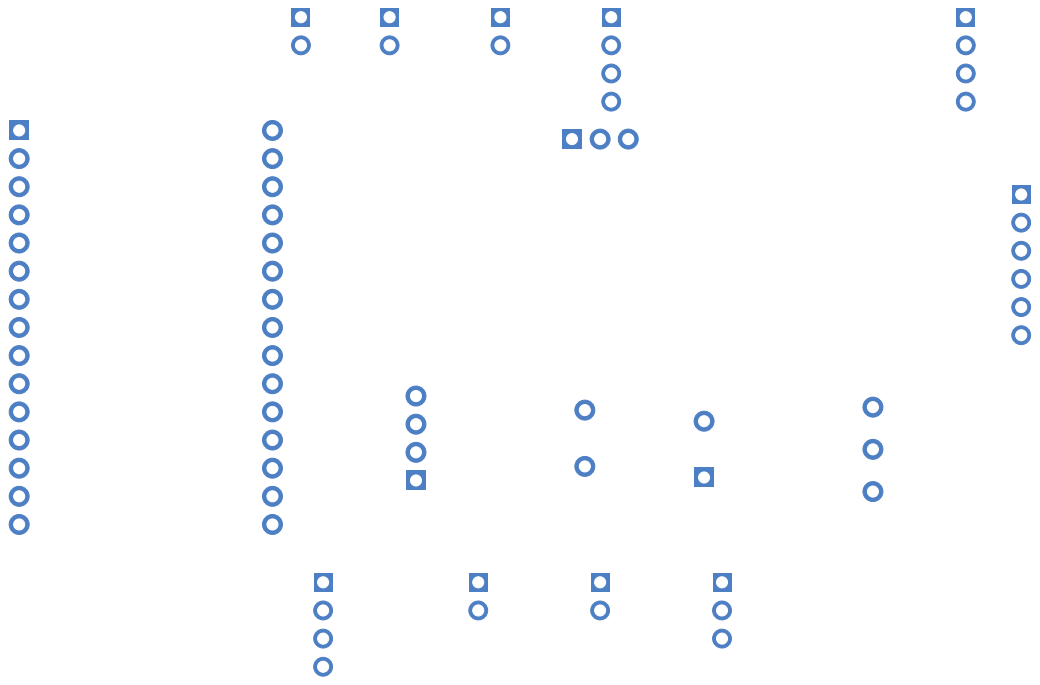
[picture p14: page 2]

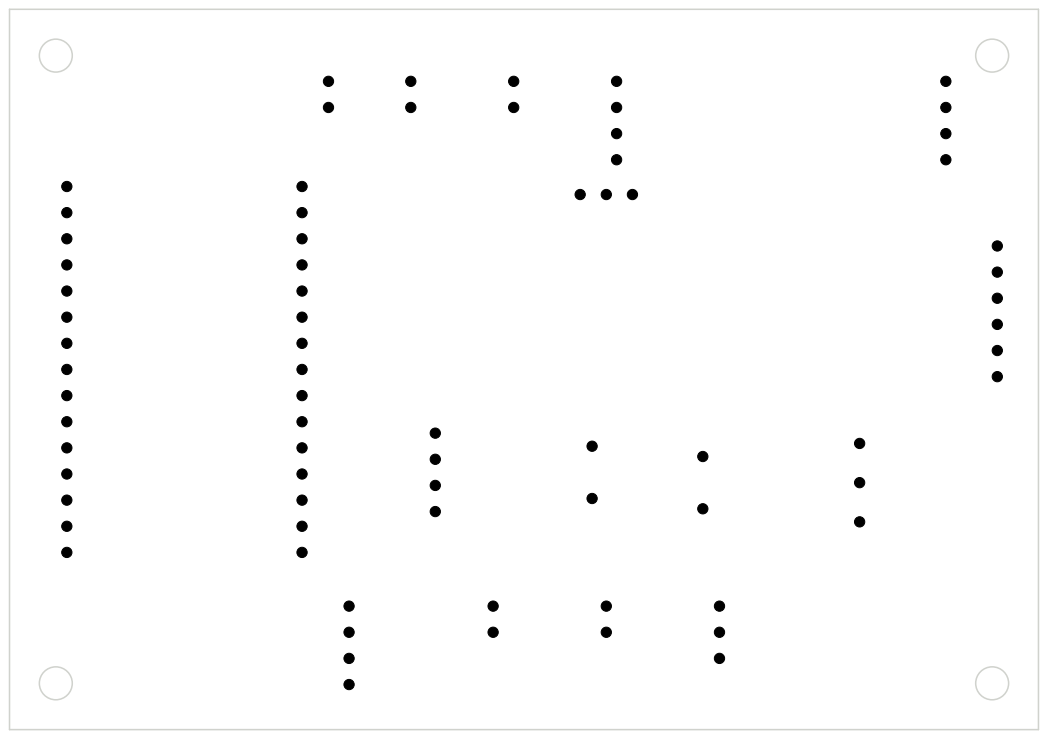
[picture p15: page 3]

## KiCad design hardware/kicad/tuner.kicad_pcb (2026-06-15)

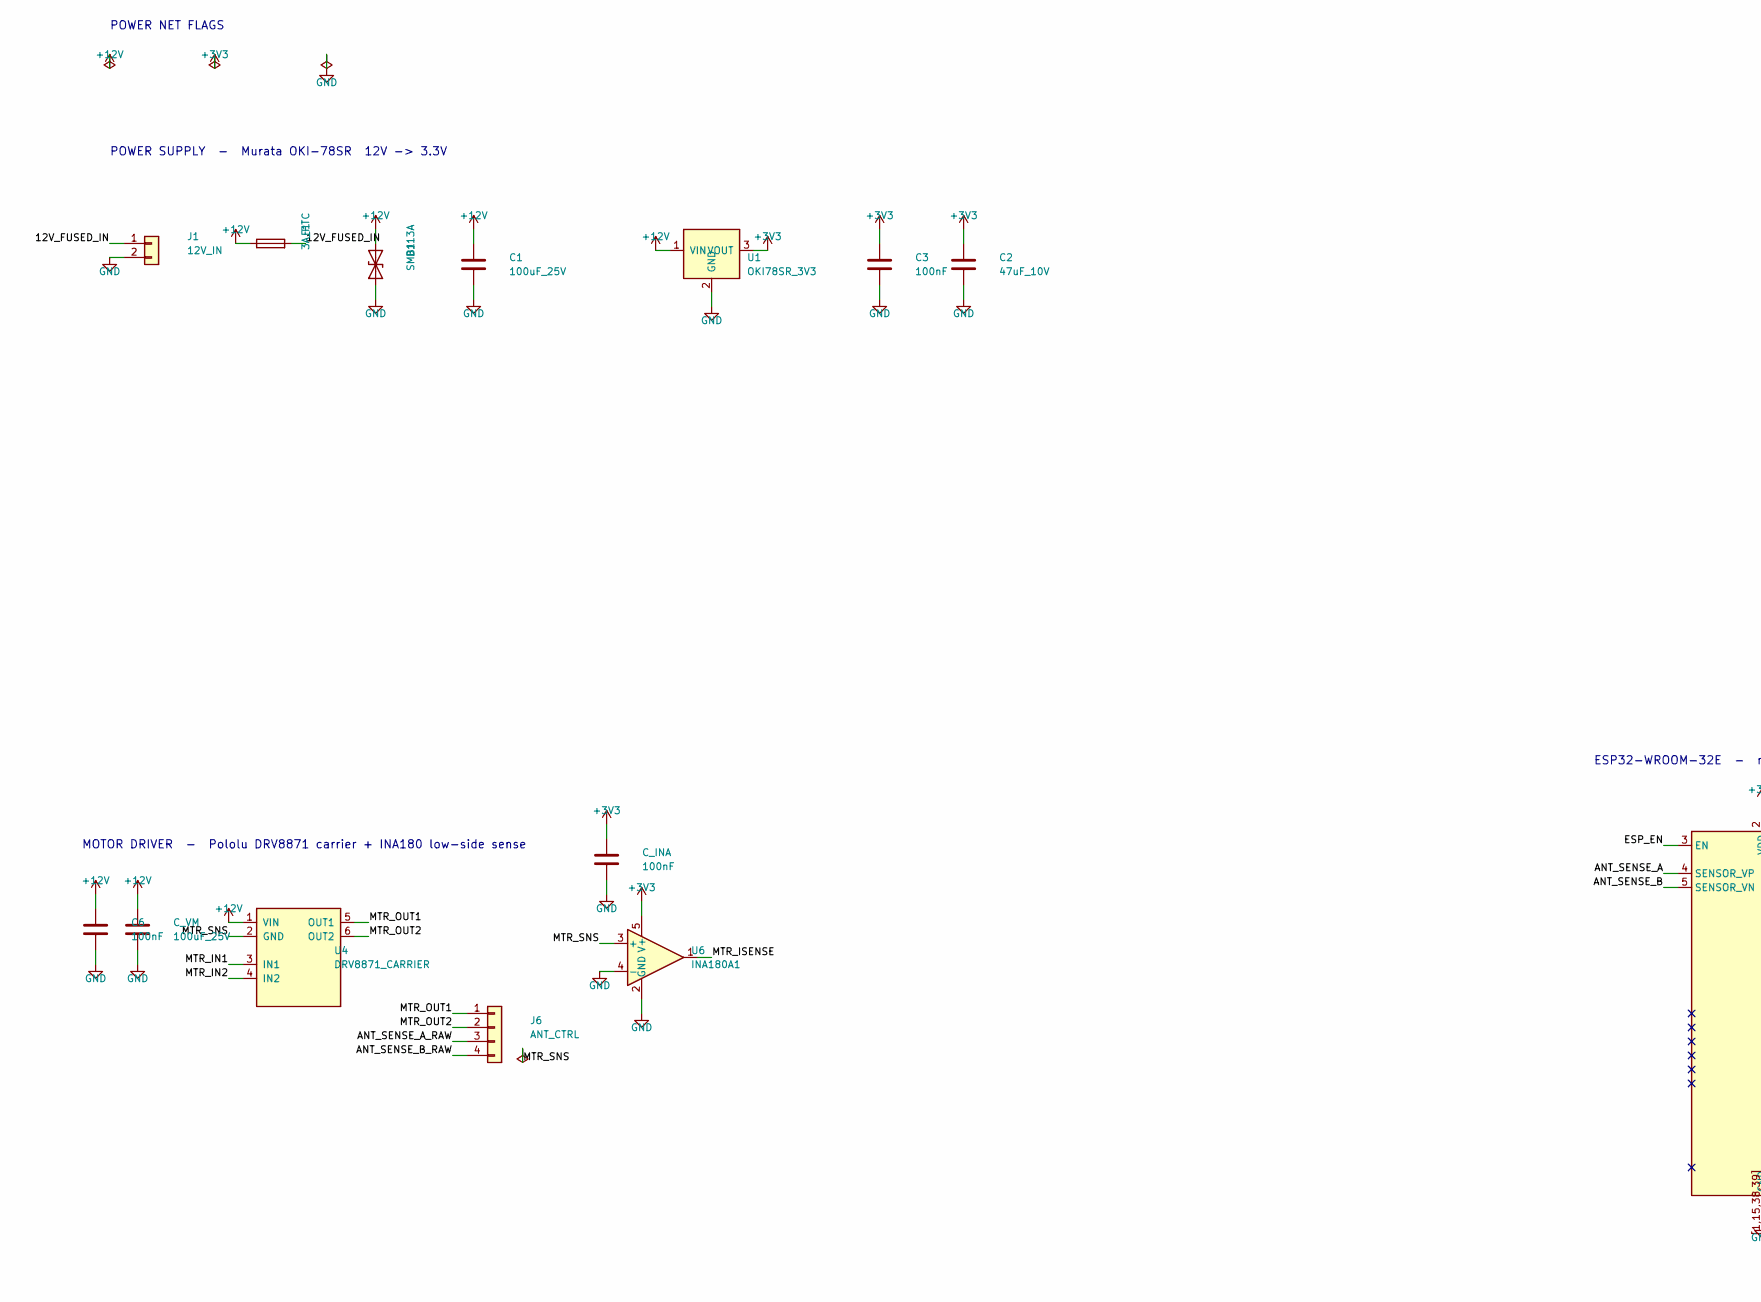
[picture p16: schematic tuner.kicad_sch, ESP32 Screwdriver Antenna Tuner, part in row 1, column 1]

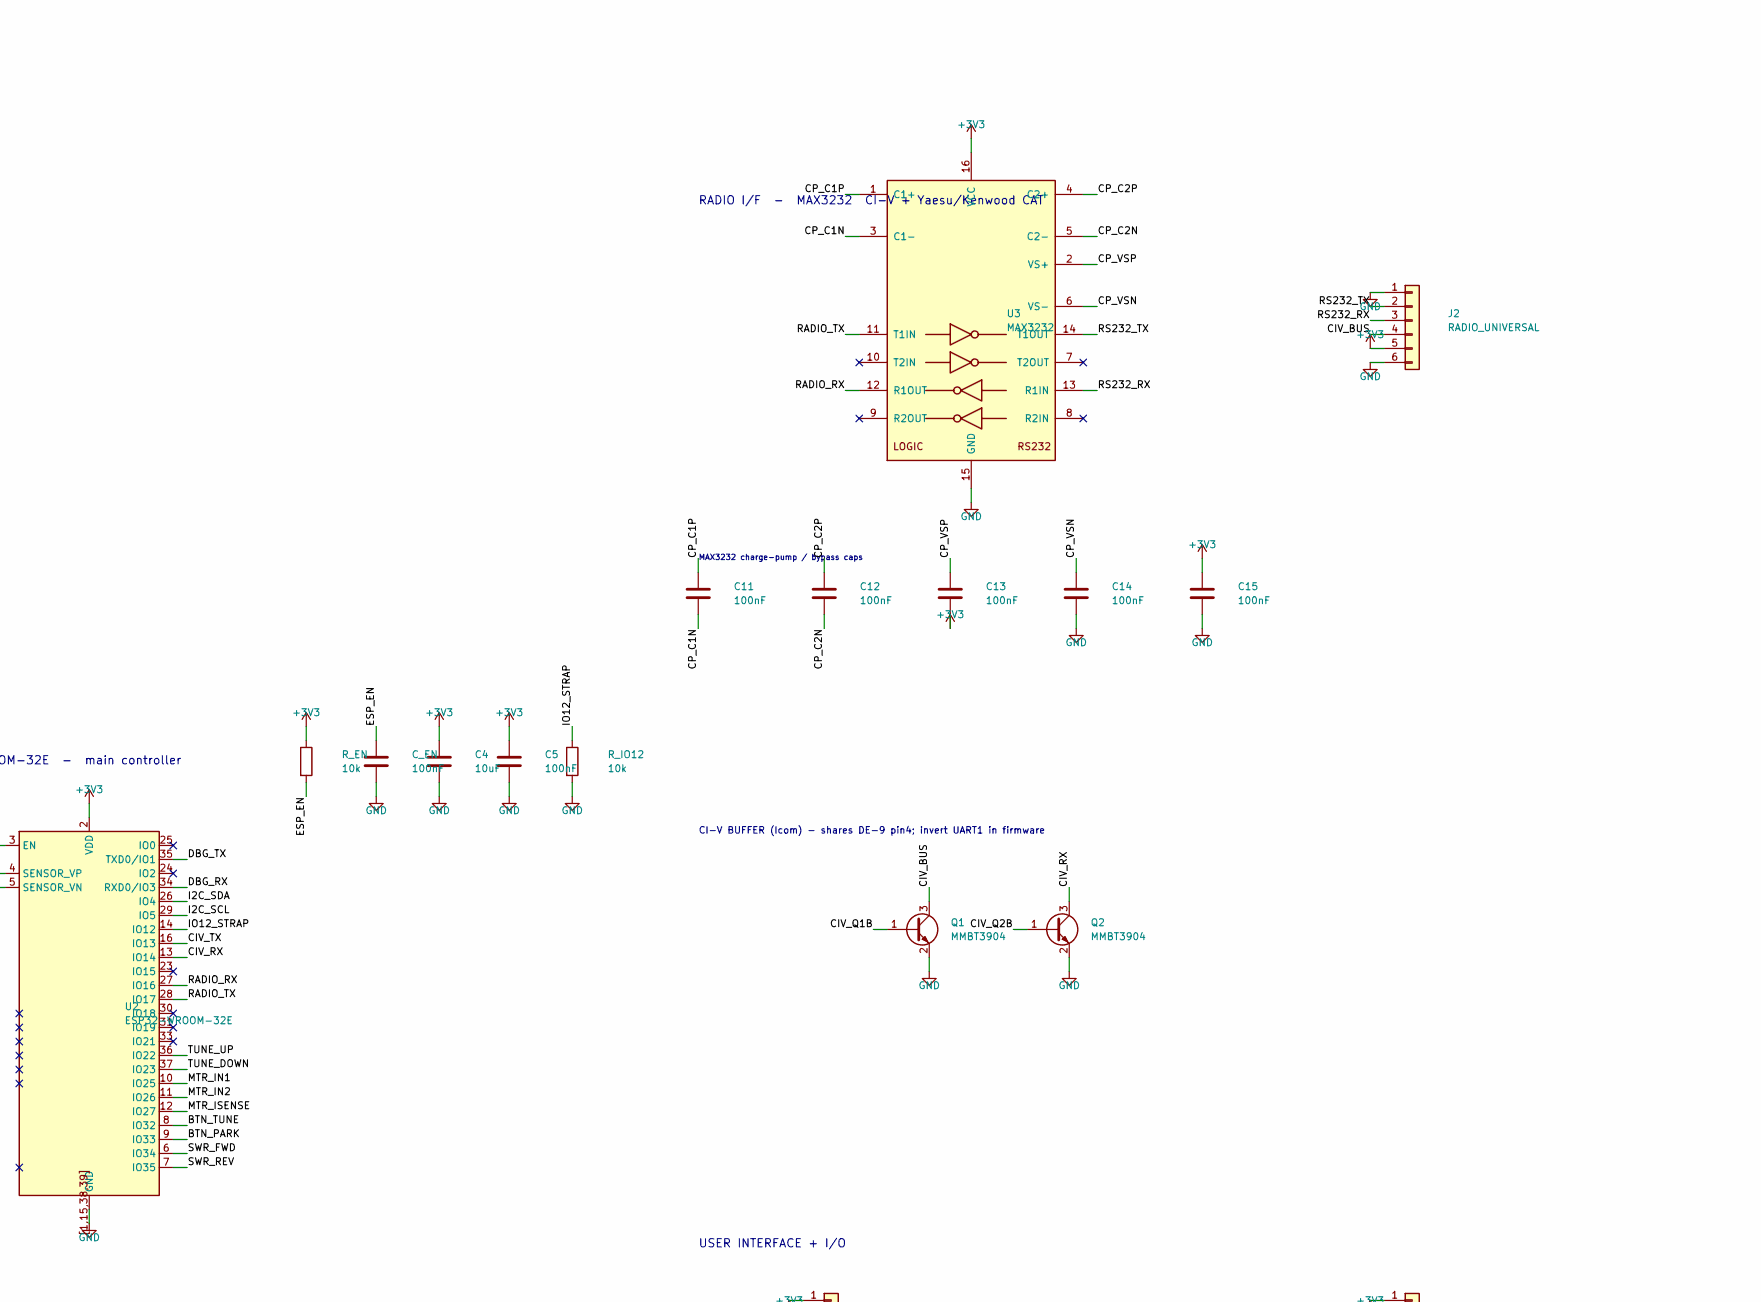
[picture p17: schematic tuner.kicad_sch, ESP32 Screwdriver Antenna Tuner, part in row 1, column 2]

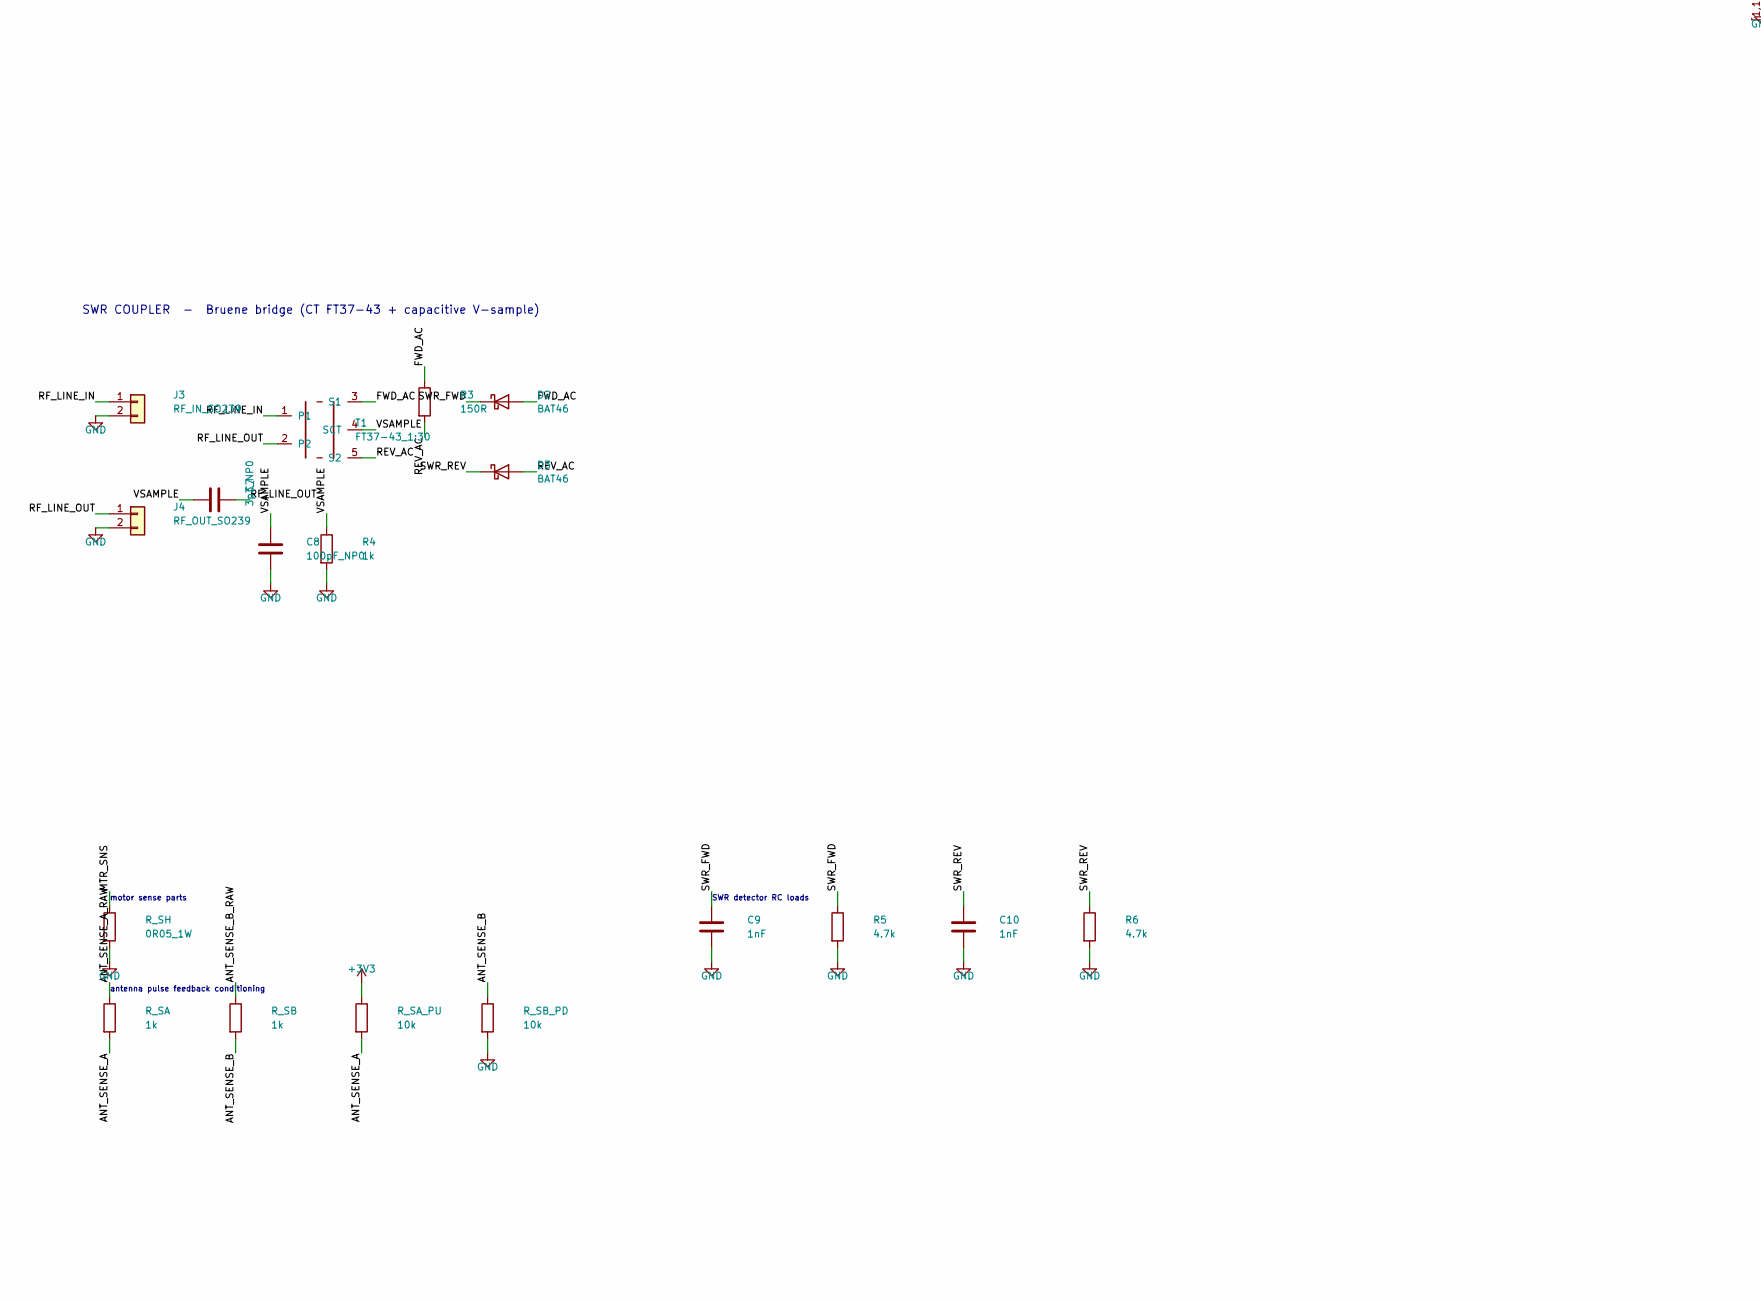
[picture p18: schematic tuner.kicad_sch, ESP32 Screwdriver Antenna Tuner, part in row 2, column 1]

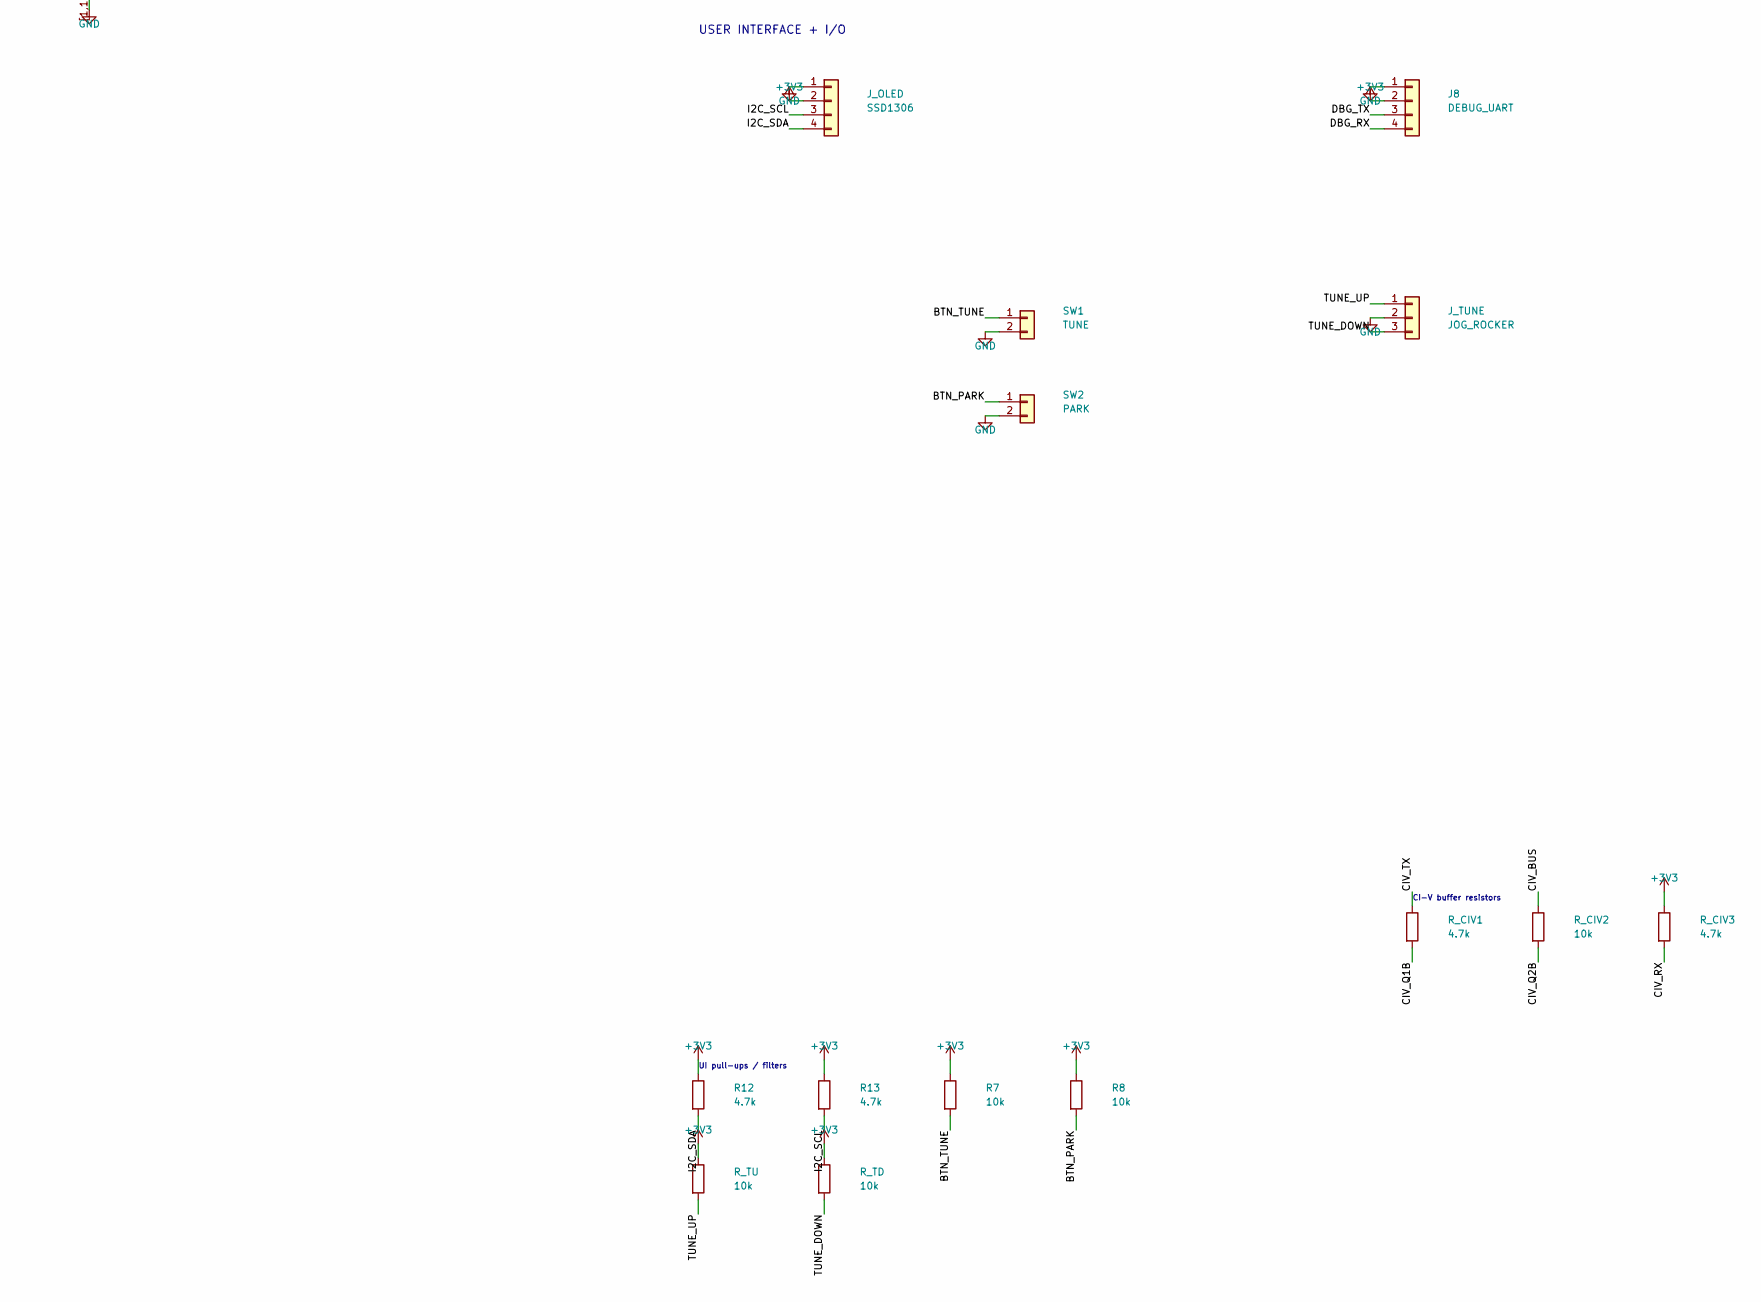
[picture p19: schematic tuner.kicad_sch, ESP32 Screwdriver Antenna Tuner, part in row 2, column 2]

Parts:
C1: 100uF_25V; CP_Elec_6.3x5.4
C2: 47uF_10V; CP_Elec_5x5.4
C3, C5, C6, C11, C12, C13, C14, C15: 100nF; C_0805_2012Metric
C4: 10uF; C_0805_2012Metric
C7: 3p3_NP0; C_0805_2012Metric
C8: 100pF_NP0; C_0805_2012Metric
C9, C10: 1nF; C_0805_2012Metric
C_EN: 100nF; C_0805_2012Metric
C_INA: 100nF; C_0805_2012Metric
C_VM: 100uF_25V; CP_Elec_6.3x5.4
D1: SMBJ13A; D_SMB; MPN SMBJ13A-E3/52
D2, D3: BAT46; D_SOD-323; MPN BAT46WJ
F1: 3A_PTC; Fuse_1812_4532Metric; MPN 1812L300PR
J1: 12V_IN; PinHeader_1x02_P2.54mm_Vertical
J2: RADIO_UNIVERSAL; PinHeader_1x06_P2.54mm_Vertical
J3: RF_IN_SO239; PinHeader_1x02_P2.54mm_Vertical
J4: RF_OUT_SO239; PinHeader_1x02_P2.54mm_Vertical
J6: ANT_CTRL; PinHeader_1x04_P2.54mm_Vertical
J8: DEBUG_UART; PinHeader_1x04_P2.54mm_Vertical
J_OLED: SSD1306; PinHeader_1x04_P2.54mm_Vertical
J_TUNE: JOG_ROCKER; PinHeader_1x03_P2.54mm_Vertical
Q1, Q2: MMBT3904; SOT-23
R3: 150R; R_0805_2012Metric
R4: 1k; R_0805_2012Metric
R5, R6, R12, R13: 4.7k; R_0805_2012Metric
R7, R8: 10k; R_0805_2012Metric
R_CIV1, R_CIV3: 4.7k; R_0805_2012Metric
R_CIV2: 10k; R_0805_2012Metric
R_EN: 10k; R_0805_2012Metric
R_IO12: 10k; R_0805_2012Metric
R_SA: 1k; R_0805_2012Metric
R_SA_PU: 10k; R_0805_2012Metric
R_SB: 1k; R_0805_2012Metric
R_SB_PD: 10k; R_0805_2012Metric
R_SH: 0R05_1W; R_2512_6332Metric
R_TD: 10k; R_0805_2012Metric
R_TU: 10k; R_0805_2012Metric
SW1: TUNE; PinHeader_1x02_P2.54mm_Vertical
SW2: PARK; PinHeader_1x02_P2.54mm_Vertical
T1: FT37-43_1:30; CT_FT37_43_Toroid
U1: OKI78SR_3V3; REG_OKI78SR; MPN OKI-78SR-3.3/1.5-W36-C
U2: ESP32-WROOM-32E; ESP32_DevKit_30; MPN ESP32 DevKit V1 30-pin (DOIT/NodeMCU-32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
U3: MAX3232; SOIC-16_3.9x9.9mm_P1.27mm; MPN MAX3232ESE+
U4: DRV8871_CARRIER
U6: INA180A1; SOT-23-5; MPN INA180A1IDBVR

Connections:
+3V3: C2.1, C3.1, C4.1, C5.1, C13.2, C15.1, C_INA.1, J2.5, J8.2, J_OLED.2, R7.1, R8.1, R12.1, R13.1, R_CIV3.1, R_EN.1, R_SA_PU.1, R_TD.1, R_TU.1, U1.3 (VOUT), U2.2 (VDD), U3.16 (VCC), U6.5 (V+)
+12V: C1.1, C6.1, C_VM.1, D1.2 (A2), F1.1, U1.1 (VIN), U4.1 (VIN)
/12V_FUSED_IN: F1.2, J1.1
/ANT_SENSE_A: R_SA.2, R_SA_PU.2, U2.4 (SENSOR_VP)
/ANT_SENSE_A_RAW: J6.3, R_SA.1
/ANT_SENSE_B: R_SB.2, R_SB_PD.1, U2.5 (SENSOR_VN)
/ANT_SENSE_B_RAW: J6.4, R_SB.1
/BTN_PARK: R8.2, SW2.1, U2.9 (IO33)
/BTN_TUNE: R7.2, SW1.1, U2.8 (IO32)
/CIV_BUS: J2.4, Q1.3 (C), R_CIV2.1
/CIV_Q1B: Q1.1 (B), R_CIV1.2
/CIV_Q2B: Q2.1 (B), R_CIV2.2
/CIV_RX: Q2.3 (C), R_CIV3.2, U2.13 (IO14)
/CIV_TX: R_CIV1.1, U2.16 (IO13)
/CP_C1N: C11.2, U3.3 (C1-)
/CP_C1P: C11.1, U3.1 (C1+)
/CP_C2N: C12.2, U3.5 (C2-)
/CP_C2P: C12.1, U3.4 (C2+)
/CP_VSN: C14.1, U3.6 (VS-)
/CP_VSP: C13.1, U3.2 (VS+)
/DBG_RX: J8.4, U2.34 (RXD0/IO3)
/DBG_TX: J8.3, U2.35 (TXD0/IO1)
/ESP_EN: C_EN.1, R_EN.2, U2.3 (EN)
/FWD_AC: D2.2 (A), R3.1, T1.3 (S1)
/I2C_SCL: J_OLED.3, R13.2, U2.29 (IO5)
/I2C_SDA: J_OLED.4, R12.2, U2.26 (IO4)
/IO12_STRAP: R_IO12.1, U2.14 (IO12)
/MTR_IN1: U2.10 (IO25), U4.3 (IN1)
/MTR_IN2: U2.11 (IO26), U4.4 (IN2)
/MTR_ISENSE: U2.12 (IO27), U6.1
/MTR_OUT1: J6.1, U4.5 (OUT1)
/MTR_OUT2: J6.2, U4.6 (OUT2)
/MTR_SNS: R_SH.1, U4.2 (GND), U6.3 (+)
/RADIO_RX: U2.27 (IO16), U3.12 (R1OUT)
/RADIO_TX: U2.28 (IO17), U3.11 (T1IN)
/REV_AC: D3.2 (A), R3.2, T1.5 (S2)
/RF_LINE_IN: J3.1, T1.1
/RF_LINE_OUT: C7.2, J4.1, T1.2
/RS232_RX: J2.3, U3.13 (R1IN)
/RS232_TX: J2.2, U3.14 (T1OUT)
/SWR_FWD: C9.1, D2.1 (K), R5.1, U2.6 (IO34)
/SWR_REV: C10.1, D3.1 (K), R6.1, U2.7 (IO35)
/TUNE_DOWN: J_TUNE.3, R_TD.2, U2.37 (IO23)
/TUNE_UP: J_TUNE.1, R_TU.2, U2.36 (IO22)
/VSAMPLE: C7.1, C8.1, R4.1, T1.4 (SCT)
GND: C1.2, C2.2, C3.2, C4.2, C5.2, C6.2, C8.2, C9.2, C10.2, C14.2, C15.2, C_EN.2, C_INA.2, C_VM.2, D1.1 (A1), J1.2, J2.1, J2.6, J3.2, J4.2, J8.1, J_OLED.1, J_TUNE.2, Q1.2 (E), Q2.2 (E), R4.2, R5.2, R6.2, R_IO12.2, R_SB_PD.2, R_SH.2, SW1.2, SW2.2, U1.2 (GND), U2.1, U2.15, U2.[1,15,38,39] (GND), U3.15 (GND), U6.2 (GND), U6.4 (-)

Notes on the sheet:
POWER NET FLAGS
POWER SUPPLY - Murata OKI-78SR 12V -> 3.3V
ESP32-WROOM-32E - main controller
MOTOR DRIVER - Pololu DRV8871 carrier + INA180 low-side sense
motor sense parts
antenna pulse feedback conditioning
SWR COUPLER - Bruene bridge (CT FT37-43 + capacitive V-sample)
SWR detector RC loads
RADIO I/F - MAX3232 CI-V + Yaesu/Kenwood CAT
MAX3232 charge-pump / bypass caps
CI-V BUFFER (Icom) - shares DE-9 pin4; invert UART1 in firmware
CI-V buffer resistors
USER INTERFACE + I/O
UI pull-ups / filters

Board: 4 copper layers, 60 parts (0 on the bottom side), 46 nets, no tracks yet.

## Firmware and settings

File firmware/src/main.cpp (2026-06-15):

#include <Arduino.h>
#include <HardwareSerial.h>
#include <Preferences.h>
#include <U8g2lib.h>
#include <Wire.h>
#include <driver/uart.h>

namespace Pins {
constexpr int I2C_SDA = 4;
constexpr int I2C_SCL = 5;

constexpr int RADIO_RX = 16;
constexpr int RADIO_TX = 17;
constexpr int CIV_TX = 13;
constexpr int CIV_RX = 14;

constexpr int MTR_IN1 = 25;
constexpr int MTR_IN2 = 26;
constexpr int MTR_ISENSE = 27;

constexpr int SWR_FWD = 34;
constexpr int SWR_REV = 35;
constexpr int ANT_SENSE_A = 36;
constexpr int ANT_SENSE_B = 39;

constexpr int BTN_TUNE = 32;
constexpr int BTN_PARK = 33;
constexpr int TUNE_UP = 22;
constexpr int TUNE_DOWN = 23;
}  // namespace Pins

namespace Cfg {
constexpr uint32_t UI_MS = 33;
constexpr uint32_t MEAS_MS = 15;
constexpr uint32_t CTRL_MS = 8;
constexpr uint32_t RADIO_POLL_MS = 220;
constexpr uint32_t FLASH_MSG_MS = 220;
constexpr uint16_t POST_STEP_MS = 450;
constexpr uint32_t UI_CHORD_HOLD_MS = 900;

constexpr uint8_t ADC_SAMPLES = 40;
constexpr float NO_RF_FWD_V = 0.05f;

constexpr uint8_t PWM_BITS = 10;
constexpr uint16_t PWM_MAX = (1u << PWM_BITS) - 1u;
constexpr uint32_t PWM_FREQ_HZ = 20000;
constexpr uint32_t SOFTSTART_MS = 140;

constexpr uint16_t DUTY_JOG = 560;
constexpr uint16_t DUTY_COARSE = 680;
constexpr uint16_t DUTY_FINE = 300;
constexpr uint16_t DUTY_PARK = 520;

constexpr float SWR_TARGET_DEFAULT = 1.30f;
constexpr float STALL_A_DEFAULT = 1.8f;
constexpr uint32_t STALL_DEBOUNCE_MS = 150;

constexpr uint32_t BTN_DEBOUNCE_MS = 20;
constexpr uint32_t TUNE_TIMEOUT_MS = 30000;
constexpr uint32_t RF_WAIT_TIMEOUT_MS = 8000;
constexpr uint32_t SAMPLE_STEP_MS = 120;
}  // namespace Cfg

enum class MotorDir : uint8_t { COAST, UP, DOWN, BRAKE };
enum class RadioBrand : uint8_t { NONE, ICOM, KENWOOD, YAESU };
enum class RadioProto : uint8_t { NONE, CIV, CAT_ASCII, YAESU_OLD_BIN };
enum class AppState : uint8_t { IDLE, TUNING, PARKING };
enum class TunePhase : uint8_t { PREP, WAIT_RF, COARSE, RETURN_BEST, CLEANUP, DONE, FAIL };
enum class DisplayPage : uint8_t { MAIN, DIAG1, DIAG2 };

struct PostResult {
  const char* title = "";
  String detail;
  bool ok = false;
};

struct FeedbackData {
  bool aLevel = true;
  bool bLevel = false;
  bool pulseSeen = false;
  bool homed = false;
  int32_t positionCounts = 0;
  uint32_t lastPulseMs = 0;
};

struct RadioConfig {
  RadioBrand brand = RadioBrand::NONE;
  RadioProto proto = RadioProto::NONE;
  uint32_t baud = 0;
  uint8_t civAddr = 0;
  bool detected = false;
};

struct CalData {
  float fwdOffsetV = 0.01f;
  float revOffsetV = 0.01f;
  float linearGain = 1.0f;
  float squareGain = 1.0f;
  float kneeV = 0.18f;
  float swrTarget = Cfg::SWR_TARGET_DEFAULT;
  float stallA = Cfg::STALL_A_DEFAULT;
};

struct MeasureData {
  float vfwd = 0.0f;
  float vrev = 0.0f;
  float pfwd = 0.0f;
  float prev = 0.0f;
  float swr = 99.0f;
  float motorCurrentA = 0.0f;
  bool carrierPresent = false;
};

class DebouncedInput {
 public:
  void begin(uint8_t pin, bool activeLow, bool usePullup) {
    pin_ = pin;
    activeLow_ = activeLow;
    pinMode(pin_, usePullup ? INPUT_PULLUP : INPUT);
    stable_ = readRaw();
    lastRaw_ = stable_;
  }

  void update(uint32_t nowMs) {
    bool raw = readRaw();
    if (raw != lastRaw_) {
      lastRaw_ = raw;
      changedMs_ = nowMs;
    }
    if ((nowMs - changedMs_) >= Cfg::BTN_DEBOUNCE_MS && stable_ != raw) {
      stable_ = raw;
      if (stable_) {
        pressedEdge_ = true;
      }
    }
  }

  bool isPressed() const { return stable_; }

  bool takePressedEdge() {
    bool e = pressedEdge_;
    pressedEdge_ = false;
    return e;
  }

 private:
  bool readRaw() const {
    bool level = digitalRead(pin_);
    return activeLow_ ? !level : level;
  }

  uint8_t pin_ = 0;
  bool activeLow_ = true;
  bool stable_ = false;
  bool lastRaw_ = false;
  bool pressedEdge_ = false;
  uint32_t changedMs_ = 0;
};

class MotorController {
 public:
  void begin() {
    pinMode(Pins::MTR_IN1, OUTPUT);
    pinMode(Pins::MTR_IN2, OUTPUT);
    ledcSetup(kChan1, Cfg::PWM_FREQ_HZ, Cfg::PWM_BITS);
    ledcSetup(kChan2, Cfg::PWM_FREQ_HZ, Cfg::PWM_BITS);
    ledcAttachPin(Pins::MTR_IN1, kChan1);
    ledcAttachPin(Pins::MTR_IN2, kChan2);
    stopCoast();
  }

  void command(MotorDir dir, uint16_t duty, uint32_t nowMs) {
    if (dir != dir_) {
      dir_ = dir;
      dirChangeMs_ = nowMs;
    }
    targetDuty_ = constrain(duty, 0u, Cfg::PWM_MAX);
    apply(nowMs);
  }

  void update(uint32_t nowMs, float motorA, float stallA) {
    apply(nowMs);
    if ((dir_ == MotorDir::UP || dir_ == MotorDir::DOWN) && targetDuty_ > 0) {
      if (motorA > stallA) {
        if (!stallArmed_) {
          stallArmed_ = true;
          stallStartMs_ = nowMs;
        } else if ((nowMs - stallStartMs_) >= Cfg::STALL_DEBOUNCE_MS) {
          stopBrake();
          stallLatched_ = true;
        }
      } else {
        stallArmed_ = false;
      }
    } else {
      stallArmed_ = false;
    }
  }

  bool takeStallLatched() {
    bool v = stallLatched_;
    stallLatched_ = false;
    return v;
  }

  MotorDir dir() const { return dir_; }

  void stopBrake() {
    dir_ = MotorDir::BRAKE;
    targetDuty_ = 0;
    currentDuty_ = 0;
    digitalWrite(Pins::MTR_IN1, HIGH);
    digitalWrite(Pins::MTR_IN2, HIGH);
  }

  void stopCoast() {
    dir_ = MotorDir::COAST;
    targetDuty_ = 0;
    currentDuty_ = 0;
    ledcWrite(kChan1, 0);
    ledcWrite(kChan2, 0);
    digitalWrite(Pins::MTR_IN1, LOW);
    digitalWrite(Pins::MTR_IN2, LOW);
  }

 private:
  void apply(uint32_t nowMs) {
    if (dir_ == MotorDir::BRAKE) {
      ledcWrite(kChan1, 0);
      ledcWrite(kChan2, 0);
      digitalWrite(Pins::MTR_IN1, HIGH);
      digitalWrite(Pins::MTR_IN2, HIGH);
      return;
    }
    if (dir_ == MotorDir::COAST) {
      ledcWrite(kChan1, 0);
      ledcWrite(kChan2, 0);
      digitalWrite(Pins::MTR_IN1, LOW);
      digitalWrite(Pins::MTR_IN2, LOW);
      return;
    }

    float ramp = min(1.0f, static_cast<float>(nowMs - dirChangeMs_) / static_cast<float>(Cfg::SOFTSTART_MS));
    currentDuty_ = static_cast<uint16_t>(targetDuty_ * ramp);
    if (dir_ == MotorDir::UP) {
      ledcWrite(kChan1, currentDuty_);
      ledcWrite(kChan2, 0);
    } else {
      ledcWrite(kChan1, 0);
      ledcWrite(kChan2, currentDuty_);
    }
  }

  static constexpr uint8_t kChan1 = 0;
  static constexpr uint8_t kChan2 = 1;

  MotorDir dir_ = MotorDir::COAST;
  uint16_t targetDuty_ = 0;
  uint16_t currentDuty_ = 0;
  uint32_t dirChangeMs_ = 0;

  bool stallArmed_ = false;
  uint32_t stallStartMs_ = 0;
  bool stallLatched_ = false;
};

class AntennaFeedback {
 public:
  void begin() {
    pinMode(Pins::ANT_SENSE_A, INPUT);
    pinMode(Pins::ANT_SENSE_B, INPUT);
    aStable_ = digitalRead(Pins::ANT_SENSE_A);
    bStable_ = digitalRead(Pins::ANT_SENSE_B);
    lastRawA_ = aStable_;
    lastRawB_ = bStable_;
  }

  void update(uint32_t nowMs, MotorDir dir) {
    bool rawA = digitalRead(Pins::ANT_SENSE_A);
    bool rawB = digitalRead(Pins::ANT_SENSE_B);

    if (rawA != lastRawA_) {
      lastRawA_ = rawA;
      lastChangeA_ = nowMs;
    }
    if (rawB != lastRawB_) {
      lastRawB_ = rawB;
      lastChangeB_ = nowMs;
    }

    if ((nowMs - lastChangeA_) >= kDebounceMs && aStable_ != rawA) {
      bool prev = aStable_;
      aStable_ = rawA;
      if (prev && !aStable_ && (dir == MotorDir::UP || dir == MotorDir::DOWN) &&
          (nowMs - lastPulseMs_) >= kMinPulseGapMs) {
        data_.pulseSeen = true;
        data_.lastPulseMs = nowMs;
        lastPulseMs_ = nowMs;
        data_.positionCounts += (dir == MotorDir::UP) ? 1 : -1;
      }
    }

    if ((nowMs - lastChangeB_) >= kDebounceMs && bStable_ != rawB) {
      bStable_ = rawB;
    }

    data_.aLevel = aStable_;
    data_.bLevel = bStable_;
  }

  void markParkedHome() {
    data_.positionCounts = 0;
    data_.homed = true;
  }

  void clearHome() { data_.homed = false; }

  const FeedbackData& data() const { return data_; }

 private:
  static constexpr uint32_t kDebounceMs = 3;
  static constexpr uint32_t kMinPulseGapMs = 5;

  FeedbackData data_{};
  bool aStable_ = true;
  bool bStable_ = false;
  bool lastRawA_ = true;
  bool lastRawB_ = false;
  uint32_t lastChangeA_ = 0;
  uint32_t lastChangeB_ = 0;
  uint32_t lastPulseMs_ = 0;
};

class RadioManager {
 public:
  void begin() {
    Serial1.begin(19200, SERIAL_8N1, Pins::CIV_RX, Pins::CIV_TX);
    uart_set_line_inverse(UART_NUM_1, UART_SIGNAL_RXD_INV | UART_SIGNAL_TXD_INV);
    Serial2.begin(9600, SERIAL_8N1, Pins::RADIO_RX, Pins::RADIO_TX);
  }

  void applyConfig(const RadioConfig& cfg) {
    cfg_ = cfg;
    if (cfg_.proto == RadioProto::CIV && cfg_.baud > 0) {
      Serial1.begin(cfg_.baud, SERIAL_8N1, Pins::CIV_RX, Pins::CIV_TX);
      uart_set_line_inverse(UART_NUM_1, UART_SIGNAL_RXD_INV | UART_SIGNAL_TXD_INV);
    }
    if ((cfg_.proto == RadioProto::CAT_ASCII || cfg_.proto == RadioProto::YAESU_OLD_BIN) && cfg_.baud > 0) {
      Serial2.begin(cfg_.baud, SERIAL_8N1, Pins::RADIO_RX, Pins::RADIO_TX);
    }
  }

  RadioConfig detect() {
    RadioConfig out{};

    const uint32_t civBauds[] = {19200, 9600, 4800};
    for (uint32_t b : civBauds) {
      Serial1.begin(b, SERIAL_8N1, Pins::CIV_RX, Pins::CIV_TX);
      uart_set_line_inverse(UART_NUM_1, UART_SIGNAL_RXD_INV | UART_SIGNAL_TXD_INV);
      if (probeCiv(out)) {
        out.detected = true;
        out.brand = RadioBrand::ICOM;
        out.proto = RadioProto::CIV;
        out.baud = b;
        cfg_ = out;
        return out;
      }
    }

    const uint32_t catBauds[] = {9600, 4800, 38400, 57600, 115200};
    for (uint32_t b : catBauds) {
      Serial2.begin(b, SERIAL_8N1, Pins::RADIO_RX, Pins::RADIO_TX);
      if (probeKenwood()) {
        out.detected = true;
        out.brand = RadioBrand::KENWOOD;
        out.proto = RadioProto::CAT_ASCII;
        out.baud = b;
        cfg_ = out;
        return out;
      }
      if (probeYaesuAscii()) {
        out.detected = true;
        out.brand = RadioBrand::YAESU;
        out.proto = RadioProto::CAT_ASCII;
        out.baud = b;
        cfg_ = out;
        return out;
      }
    }

    out.detected = false;
    out.brand = RadioBrand::NONE;
    out.proto = RadioProto::NONE;
    out.baud = 0;
    cfg_ = out;
    return out;
  }

  bool readFrequencyHz(uint64_t& outHz) {
    if (!cfg_.detected) return false;
    if (cfg_.proto == RadioProto::CIV) return readCivFrequency(outHz);
    if (cfg_.proto == RadioProto::CAT_ASCII) return readAsciiFrequency(outHz);
    return false;
  }

  bool enterLowPowerTune() {
    if (!cfg_.detected) return false;
    if (cfg_.proto == RadioProto::CAT_ASCII) {
      Serial2.print("PC005;");
      String rsp = readAsciiReply(Serial2, 120);
      (void)rsp;
      return true;
    }
    if (cfg_.proto == RadioProto::CIV) {
      uint8_t addr = (cfg_.civAddr == 0) ? 0x00 : cfg_.civAddr;
      // CI-V power set command (scaled) and PTT handled separately.
      uint8_t cmd[] = {0xFE, 0xFE, addr, 0xE0, 0x14, 0x0A, 0x01, 0x00, 0xFD};
      Serial1.write(cmd, sizeof(cmd));
      return true;
    }
    return false;
  }

  bool keyCarrier(bool on) {
    if (!cfg_.detected) return false;
    if (cfg_.proto == RadioProto::CAT_ASCII) {
      Serial2.print(on ? "TX;" : "RX;");
      return true;
    }
    if (cfg_.proto == RadioProto::CIV) {
      uint8_t addr = (cfg_.civAddr == 0) ? 0x00 : cfg_.civAddr;
      uint8_t cmd[] = {0xFE, 0xFE, addr, 0xE0, 0x1C, 0x00, static_cast<uint8_t>(on ? 0x01 : 0x00), 0xFD};
      Serial1.write(cmd, sizeof(cmd));
      return true;
    }
    return false;
  }

  bool restorePower() {
    if (!cfg_.detected) return false;
    // Placeholder: in this first pass we force low-power tune and rely on manual restoration if needed.
    // Keeping function for later model-specific restoration commands.
    return true;
  }

  const RadioConfig& config() const { return cfg_; }

 private:
  static void flush(HardwareSerial& s) {
    while (s.available()) s.read();
  }

  static String readAsciiReply(HardwareSerial& s, uint32_t timeoutMs) {
    String out;
    uint32_t start = millis();
    while ((millis() - start) < timeoutMs) {
      while (s.available()) {
        char c = static_cast<char>(s.read());
        out += c;
        if (c == ';') return out;
      }
      delay(1);
    }
    return out;
  }

  static size_t readUntilFd(HardwareSerial& s, uint8_t* out, size_t maxLen, uint32_t timeoutMs) {
    size_t n = 0;
    uint32_t start = millis();
    while ((millis() - start) < timeoutMs && n < maxLen) {
      while (s.available() && n < maxLen) {
        out[n++] = static_cast<uint8_t>(s.read());
        if (out[n - 1] == 0xFD) return n;
      }
      delay(1);
    }
    return n;
  }

  bool probeCiv(RadioConfig& out) {
    flush(Serial1);
    uint8_t cmd[] = {0xFE, 0xFE, 0x00, 0xE0, 0x03, 0xFD};
    Serial1.write(cmd, sizeof(cmd));
    uint8_t frame[32] = {0};
    size_t n = readUntilFd(Serial1, frame, sizeof(frame), 160);
    if (n < 6 || frame[0] != 0xFE || frame[1] != 0xFE || frame[n - 1] != 0xFD) return false;
    if (frame[2] != 0xE0) return false;
    out.civAddr = frame[3];
    return true;
  }

  bool probeKenwood() {
    flush(Serial2);
    Serial2.print("ID;");
    String rsp = readAsciiReply(Serial2, 160);
    return rsp.startsWith("ID") && rsp.endsWith(";");
  }

  bool probeYaesuAscii() {
    flush(Serial2);
    Serial2.print("FA;");
    String rsp = readAsciiReply(Serial2, 160);
    return rsp.startsWith("FA") && rsp.endsWith(";") && rsp.length() >= 5;
  }

  bool readCivFrequency(uint64_t& outHz) {
    flush(Serial1);
    uint8_t addr = (cfg_.civAddr == 0) ? 0x00 : cfg_.civAddr;
    uint8_t cmd[] = {0xFE, 0xFE, addr, 0xE0, 0x03, 0xFD};
    Serial1.write(cmd, sizeof(cmd));

    uint8_t frame[40] = {0};
    size_t n = readUntilFd(Serial1, frame, sizeof(frame), 160);
    if (n < 8 || frame[0] != 0xFE || frame[1] != 0xFE || frame[n - 1] != 0xFD || frame[4] != 0x03) return false;

    uint64_t f = 0;
    uint64_t place = 1;
    for (size_t i = 5; i < n - 1; ++i) {
      uint8_t b = frame[i];
      uint8_t lo = b & 0x0F;
      uint8_t hi = (b >> 4) & 0x0F;
      if (lo > 9 || hi > 9) return false;
      f += static_cast<uint64_t>(lo) * place;
      place *= 10;
      f += static_cast<uint64_t>(hi) * place;
      place *= 10;
    }
    outHz = f;
    return true;
  }

  bool readAsciiFrequency(uint64_t& outHz) {
    flush(Serial2);
    Serial2.print("FA;");
    String rsp = readAsciiReply(Serial2, 160);
    if (!rsp.startsWith("FA") || !rsp.endsWith(";")) return false;
    String digits = rsp.substring(2, rsp.length() - 1);
    uint64_t f = 0;
    for (size_t i = 0; i < digits.length(); ++i) {
      char c = digits[i];
      if (c < '0' || c > '9') return false;
      f = f * 10 + static_cast<uint64_t>(c - '0');
    }
    outHz = f;
    return true;
  }

  RadioConfig cfg_{};
};

U8G2_SSD1306_128X64_NONAME_F_HW_I2C g_oled(U8G2_R0, U8X8_PIN_NONE);
Preferences g_pref;
MotorController g_motor;
RadioManager g_radio;
AntennaFeedback g_feedback;

DebouncedInput g_btnTune;
DebouncedInput g_btnPark;
DebouncedInput g_btnUp;
DebouncedInput g_btnDown;

CalData g_cal{};
MeasureData g_meas{};
RadioConfig g_radioCfg{};

AppState g_state = AppState::IDLE;
TunePhase g_tunePhase = TunePhase::DONE;
String g_status = "READY";
uint64_t g_freqHz = 0;
String g_flashMessage;
uint8_t g_flashTogglesRemaining = 0;
bool g_flashVisible = false;
uint32_t g_flashNextMs = 0;
DisplayPage g_displayPage = DisplayPage::MAIN;
uint32_t g_uiChordStartMs = 0;
bool g_uiChordLatched = false;
uint8_t g_postFailCount = 0;
PostResult g_postResults[8];
uint8_t g_postResultCount = 0;

uint32_t g_lastUiMs = 0;
uint32_t g_lastMeasMs = 0;
uint32_t g_lastCtrlMs = 0;
uint32_t g_lastRadioMs = 0;
uint32_t g_tuneStartMs = 0;
uint32_t g_lastStepMs = 0;

int32_t g_sweepIdx = 0;
int32_t g_bestIdx = 0;
float g_bestSwr = 99.0f;
uint8_t g_reversals = 0;
uint8_t g_worseCount = 0;
MotorDir g_sweepDir = MotorDir::UP;
bool g_keyed = false;
int32_t g_tuneOriginCounts = 0;
int32_t g_bestPositionCounts = 0;

bool feedbackTrackingReady() {
  const FeedbackData& fb = g_feedback.data();
  return fb.homed && fb.pulseSeen;
}

void startFlashMessage(const char* msg, uint8_t flashes) {
  if (flashes == 0) return;
  g_flashMessage = msg;
  g_flashTogglesRemaining = flashes * 2;
  g_flashVisible = true;
  g_flashNextMs = millis() + Cfg::FLASH_MSG_MS;
}

void serviceFlashMessage(uint32_t now) {
  if (g_flashTogglesRemaining == 0) return;
  if (now < g_flashNextMs) return;

  g_flashVisible = !g_flashVisible;
  if (g_flashTogglesRemaining > 0) {
    g_flashTogglesRemaining--;
  }
  g_flashNextMs = now + Cfg::FLASH_MSG_MS;
  if (g_flashTogglesRemaining == 0) {
    g_flashVisible = false;
    g_flashMessage = "";
  }
}

void postScreen(const char* title, const char* detail, bool ok) {
  if (!ok && g_postFailCount < 255) g_postFailCount++;
  if (g_postResultCount < (sizeof(g_postResults) / sizeof(g_postResults[0]))) {
    g_postResults[g_postResultCount].title = title;
    g_postResults[g_postResultCount].detail = detail;
    g_postResults[g_postResultCount].ok = ok;
    g_postResultCount++;
  }
  Serial.printf("POST %-12s : %s\n", title, detail);
  g_oled.clearBuffer();
  g_oled.setFont(u8g2_font_6x12_tr);
  g_oled.drawStr(0, 12, "POWER-ON SELF TEST");
  g_oled.drawStr(0, 28, title);
  g_oled.drawStr(0, 42, detail);
  g_oled.drawStr(0, 58, ok ? "RESULT: OK" : "RESULT: CHECK");
  g_oled.sendBuffer();
  delay(Cfg::POST_STEP_MS);
}

void printPostSummary() {
  Serial.println("POST summary table");
  Serial.println("-------------------------------");
  for (uint8_t i = 0; i < g_postResultCount; ++i) {
    Serial.printf("%-12s | %-5s | %s\n",
                  g_postResults[i].title,
                  g_postResults[i].ok ? "OK" : "CHECK",
                  g_postResults[i].detail.c_str());
  }
  Serial.println("-------------------------------");
}

bool anyControlPressedRaw() {
  return !digitalRead(Pins::BTN_TUNE) || !digitalRead(Pins::BTN_PARK) ||
         !digitalRead(Pins::TUNE_UP) || !digitalRead(Pins::TUNE_DOWN);
}

void waitForPostAcknowledge() {
  if (g_postFailCount == 0) return;

  Serial.printf("POST summary: %u check(s) need attention\n", g_postFailCount);
  while (anyControlPressedRaw()) delay(5);

  while (true) {
    g_oled.clearBuffer();
    g_oled.setFont(u8g2_font_6x12_tr);
    g_oled.drawStr(0, 12, "POST NEEDS REVIEW");
    g_oled.drawStr(0, 28, "Check serial log");
    g_oled.drawStr(0, 42, "Press any button");
    char line[24];
    snprintf(line, sizeof(line), "Failures: %u", g_postFailCount);
    g_oled.drawStr(0, 58, line);
    g_oled.sendBuffer();
    if (anyControlPressedRaw()) break;
    delay(20);
  }

  while (anyControlPressedRaw()) delay(5);
}

int readAveragedAdc(int pin, uint8_t samples) {
  uint32_t sum = 0;
  for (uint8_t i = 0; i < samples; ++i) sum += analogRead(pin);
  return static_cast<int>(sum / samples);
}

float adcToVolts(int adcRaw) {
  return (static_cast<float>(adcRaw) / 4095.0f) * 3.3f;
}

float detectorToPower(const CalData& cal, float v) {
  float vv = max(0.0f, v);
  if (vv < cal.kneeV) return vv * cal.linearGain;
  return (vv - cal.kneeV) * (vv - cal.kneeV) * cal.squareGain + cal.kneeV * cal.linearGain;
}

void loadCal() {
  g_pref.begin("cal", true);
  g_cal.fwdOffsetV = g_pref.getFloat("fo", g_cal.fwdOffsetV);
  g_cal.revOffsetV = g_pref.getFloat("ro", g_cal.revOffsetV);
  g_cal.linearGain = g_pref.getFloat("lg", g_cal.linearGain);
  g_cal.squareGain = g_pref.getFloat("sg", g_cal.squareGain);
  g_cal.kneeV = g_pref.getFloat("kv", g_cal.kneeV);
  g_cal.swrTarget = g_pref.getFloat("swrT", g_cal.swrTarget);
  g_cal.stallA = g_pref.getFloat("stallA", g_cal.stallA);
  g_pref.end();
}

void loadRadioCfg() {
  g_pref.begin("radio", true);
  g_radioCfg.brand = static_cast<RadioBrand>(g_pref.getUChar("brand", static_cast<uint8_t>(RadioBrand::NONE)));
  g_radioCfg.proto = static_cast<RadioProto>(g_pref.getUChar("proto", static_cast<uint8_t>(RadioProto::NONE)));
  g_radioCfg.baud = g_pref.getUInt("baud", 0);
  g_radioCfg.civAddr = g_pref.getUChar("addr", 0);
  g_radioCfg.detected = g_pref.getBool("det", false);
  g_pref.end();
}

void saveRadioCfg() {
  g_pref.begin("radio", false);
  g_pref.putUChar("brand", static_cast<uint8_t>(g_radioCfg.brand));
  g_pref.putUChar("proto", static_cast<uint8_t>(g_radioCfg.proto));
  g_pref.putUInt("baud", g_radioCfg.baud);
  g_pref.putUChar("addr", g_radioCfg.civAddr);
  g_pref.putBool("det", g_radioCfg.detected);
  g_pref.end();
}
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
void loop() {
  uint32_t now = millis();
  serviceFlashMessage(now);

  if ((now - g_lastCtrlMs) >= Cfg::CTRL_MS) {
    g_lastCtrlMs = now;
    g_btnTune.update(now);
    g_btnPark.update(now);
    g_btnUp.update(now);
    g_btnDown.update(now);
    g_feedback.update(now, g_motor.dir());
  }

  if ((now - g_lastMeasMs) >= Cfg::MEAS_MS) {
    g_lastMeasMs = now;
    updateMeasurements();
  }

  g_motor.update(now, g_meas.motorCurrentA, g_cal.stallA);

  if (g_state == AppState::IDLE) {
    serviceIdleControls();
  } else if (g_state == AppState::TUNING) {
    serviceTune();
  } else if (g_state == AppState::PARKING) {
    if (g_btnTune.takePressedEdge() || g_btnUp.isPressed() || g_btnDown.isPressed()) {
      g_motor.stopBrake();
      g_state = AppState::IDLE;
      g_status = "ABORT";
    } else {
      servicePark();
    }
  }

  if ((now - g_lastRadioMs) >= Cfg::RADIO_POLL_MS) {
    g_lastRadioMs = now;
    uint64_t f = 0;
    if (g_radio.readFrequencyHz(f)) g_freqHz = f;
  }

  if ((now - g_lastUiMs) >= Cfg::UI_MS) {
    g_lastUiMs = now;
    drawUi();
  }

  delay(1);
}

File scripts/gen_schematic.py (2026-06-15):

#!/usr/bin/env python3
"""
Generate tuner.kicad_sch for KiCad 10  —  label-driven (netlist-style) schematic.

Design philosophy (why this is ERC-clean by construction):
  * KiCad's native grid is 1.27 mm (50 mil). ALL geometry is built on it.
  * Symbol pin tips are read directly from the installed library, so every
    coordinate is exact.
  * There are NO long inter-component wires. Every pin gets a short 2.54 mm
    stub terminated by either a net label (signals) or a power symbol
    (power/ground). Components connect purely by matching label names.
    => wires cannot "miss" a pin, and there are no dangling endpoints.
  * Unused MCU IO pins get explicit no-connect markers.
  * Each power net carries a PWR_FLAG so ERC sees it as driven.

Run from the project root (tuner/):  python3 scripts/gen_schematic.py
Validate: flatpak run --command=kicad-cli org.kicad.KiCad sch erc tuner.kicad_sch -o erc.json --format json
"""

import re, math, os

KICAD = os.path.abspath(os.path.join(          # the kicad project dir (../hardware/kicad)
    os.path.dirname(os.path.abspath(__file__)), "..", "hardware", "kicad"))
LIBDIR = ("/var/lib/flatpak/runtime/org.kicad.KiCad.Library.Symbols/x86_64/stable/"
          "3b7929bb14971a6b04bc640443a65ebdfa78dc56d399fae4f24c1834540307a9/files/symbols")

G    = 1.27       # KiCad native grid (mm)
STUB = 2 * G      # 2.54 mm pin stub length
# Global sheet offset so the drawing sits CENTRED on the A1 sheet (841x594mm).
# Multiples of G so pins stay on grid. (Content span ~588x446; these centre it.)
OX, OY = 86 * G, 41 * G    # 109.22, 52.07 mm
ROOT_UUID = "00000000-0000-0000-0000-000000000001"
PROJECT   = "tuner"

def instances_block(ref, unit=1, indent="    "):
    """Required so KiCad instantiates the symbol (connectivity + annotation)."""
    return (f'{indent}(instances\n'
            f'{indent}  (project "{PROJECT}"\n'
            f'{indent}    (path "/{ROOT_UUID}"\n'
            f'{indent}      (reference "{ref}") (unit {unit})\n'
            f'{indent}    )\n'
            f'{indent}  )\n'
            f'{indent})')

_pwr_ctr = [0]
def next_pwr_ref():
    _pwr_ctr[0] += 1
    return f"#PWR{_pwr_ctr[0]:04d}"

_flg_ctr = [0]
def next_flg_ref():
    _flg_ctr[0] += 1
    return f"#FLG{_flg_ctr[0]:04d}"

# ── Unique id counter (deterministic) ──────────────────────────────────────
_uid = 0
def uid():
    global _uid
    _uid += 1
    return f"00000000-0000-0000-0000-{_uid:012x}"

def gsnap(v):
    return round(round(v / G) * G, 4)

def sign(v):
    return 0 if abs(v) < 1e-9 else (1 if v > 0 else -1)

# ── Custom (locally-defined) symbols ───────────────────────────────────────
# For parts not in the installed libraries (e.g. a hand-wound current
# transformer). Each entry: name -> (lib_symbols_text, {num:(x,y,ang)}, {pname:num})
CUSTOM = {}

def _register_custom(name, body, pins):
    """pins: list of (num, pname, x, y, ang). Builds a minimal valid lib symbol."""
    pmap, n2n = {}, {}
    pin_sexprs = []
    for num, pname, x, y, ang in pins:
        pmap[num] = (x, y, ang)
        if pname:
            n2n[pname] = num
        pin_sexprs.append(
            f'      (pin passive line (at {x} {y} {ang}) (length 2.54)\n'
            f'        (name "{pname}" (effects (font (size 1.27 1.27))))\n'
            f'        (number "{num}" (effects (font (size 1.27 1.27)))))')
    text = (
        f'    (symbol "Tuner:{name}"\n'
        f'      (pin_names (offset 1.016)) (in_bom yes) (on_board yes)\n'
        f'      (property "Reference" "T" (at 0 7.62 0) (effects (font (size 1.27 1.27))))\n'
        f'      (property "Value" "{name}" (at 0 -7.62 0) (effects (font (size 1.27 1.27))))\n'
        f'      (property "Footprint" "" (at 0 0 0) (effects (font (size 1.27 1.27)) (hide yes)))\n'
        f'      (property "Datasheet" "" (at 0 0 0) (effects (font (size 1.27 1.27)) (hide yes)))\n'
        f'      (symbol "{name}_0_1"\n{body}\n      )\n'
        f'      (symbol "{name}_1_1"\n' + "\n".join(pin_sexprs) + '\n      )\n'
        f'    )')
    CUSTOM[name] = (text, pmap, n2n)

# Current transformer for the Bruene directional coupler (FT37-43, 1T:Ns,
# centre-tapped secondary). P1/P2 = through-line (1 turn); S1/SCT/S2 = secondary.
_register_custom(
    "CT_FT37_43",
    body=(
        '        (polyline (pts (xy -2.54 5.08) (xy -2.54 -5.08)) (stroke (width 0.3)))\n'
        '        (polyline (pts (xy  2.54 5.08) (xy  2.54 -5.08)) (stroke (width 0.3)))\n'
        '        (polyline (pts (xy -0.5 5.08) (xy 0.5 5.08)) (stroke (width 0)))\n'
        '        (polyline (pts (xy -0.5 -5.08) (xy 0.5 -5.08)) (stroke (width 0)))'),
    pins=[
        ("1", "P1",  -7.62,  2.54, 0),
        ("2", "P2",  -7.62, -2.54, 0),
        ("3", "S1",   7.62,  5.08, 180),
        ("4", "SCT",  7.62,  0.0,  180),
        ("5", "S2",   7.62, -5.08, 180),
    ])

# Murata OKI-78SR fixed 3.3V SIP regulator. TO-220 compatible 3-pin module.
_register_custom(
    "REG_OKI78SR",
    body='        (rectangle (start -5.08 6.35) (end 5.08 -2.54) (stroke (width 0.254)) (fill (type background)))',
    pins=[
        ("1", "VIN",  -7.62,  2.54, 0),
        ("2", "GND",   0.0,  -5.08, 90),
        ("3", "VOUT",  7.62,  2.54, 180),
    ])

# Pololu DRV8871 single-brushed-DC motor driver carrier. Socketed module.
_register_custom(
    "DRV8871_CARRIER",
    body='        (rectangle (start -7.62 8.89) (end 7.62 -8.89) (stroke (width 0.254)) (fill (type background)))',
    pins=[
        ("1", "VIN",  -10.16,  6.35, 0),
        ("2", "GND",  -10.16,  3.81, 0),
        ("3", "IN1",  -10.16, -1.27, 0),
        ("4", "IN2",  -10.16, -3.81, 0),
        ("5", "OUT1",  10.16,  6.35, 180),
        ("6", "OUT2",  10.16,  3.81, 180),
    ])

# ── Library symbol extraction ──────────────────────────────────────────────
_LIB_CACHE = {}
def _libtext(lib_file):
    if lib_file not in _LIB_CACHE:
        _LIB_CACHE[lib_file] = open(f"{LIBDIR}/{lib_file}").read()
    return _LIB_CACHE[lib_file]

def _symbol_block(content, name):
    start = content.find(f'\t(symbol "{name}"\n')
    if start == -1:
        return None
    depth = 0
    for i in range(start, len(content)):
        if content[i] == '(':
            depth += 1
        elif content[i] == ')':
            depth -= 1
            if depth == 0:
                return content[start:i + 1]
    return None

def _iter_properties(block):
    """Yield (key, full_sexpr_text) for each top-level (property "K" ...) in block."""
    i = 0
    while True:
        j = block.find('(property "', i)
        if j == -1:
            return
        key = block[j + len('(property "'):block.find('"', j + len('(property "'))]
        depth = 0
        for k in range(j, len(block)):
            if block[k] == '(':
                depth += 1
            elif block[k] == ')':
                depth -= 1
                if depth == 0:
                    yield key, block[j:k + 1]
                    i = k + 1
                    break
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

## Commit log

2026-06-15 Initial tuner firmware and hardware baseline
    [BOM.csv, enclosure.scad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]
2026-06-15 Revise power stage and refresh hardware artifacts
    [BOM.csv, enclosure.scad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]
2026-06-15 Add print assets and builder checklist
    [base.3mf, base.stl, enclosure_full.3mf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]
2026-06-15 Fix lid pass-through placement and refresh print assets
    [base.3mf, base.stl, enclosure.scad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]
2026-06-15 Switch jog to through-button holes and add enclosure engravings
    [base.3mf, base.stl, enclosure.scad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]
2026-06-15 Finalize assembly notes and enclosure artifact refresh
    [enclosure_full.3mf]
